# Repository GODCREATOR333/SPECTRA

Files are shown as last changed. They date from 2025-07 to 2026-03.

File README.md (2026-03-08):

## Abstract  
SPECTRA is a **laser steering system** based on a single-stage, direct-drive galvanometer.  
It uses a **voice-coil actuator** with a mirror assembly for high-speed angular control.  
A **custom differential photodiode position sensor** is being developed for feedback in this configuration.  

---

## Current Status  
- Functional CAD prototype fabricated and tested.  
- Operated at ~10% scanning speed in open-loop mode.  
- Closed-loop implementation (PID, LQR, MPC) under development.  

---

## Figures  

**Prototype:**  
SPECTRA CAD Prototype  

**Demonstration Video:**
Demo video

**Custom Physics Engine To Simulate Ray-plane intersection, Forward Kinematics, Inverse Kinematics, Control Strategies**
phy_engine_demo

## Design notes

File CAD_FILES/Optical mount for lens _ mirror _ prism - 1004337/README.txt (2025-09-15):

Optical mount for lens / mirror / prism  by dmarett on Thingiverse: https://www.thingiverse.com/thing:1004337

Summary:
This is a kinematic optical platform mount designed to fit onto a regular optical breadboard using 1/4-20 mounting holes (or metric).  It uses a mounting arm (PM1 style, see separate PM1 file ) to hold a square optical component against the lower platform. It uses 6-32 screws with knobs to control the movement of the platform left-right and pivot up-down. Mounting screw is 6-32 and can mount onto a steel 1/2 inch post with a 6-32 thread, or a 3D printed post (see separate file). The component requires a number of metal parts:Parts:2  6-32 x 3/8" internally threaded standoffs4  6-32 nuts1 6-32 x 1/4" screw2  6-32 x 1/2" screws (platform mount)2  6-32 x 1.5" screws1  6-32 x 3/4" screw (ball mount)2  1/2" springs with hook ends4  7/16" x 1/16" aluminum pins

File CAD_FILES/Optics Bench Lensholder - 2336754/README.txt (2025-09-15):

Optics Bench Lensholder by polyfractal on Thingiverse: https://www.thingiverse.com/thing:2336754

Summary:
Optical benches are expensive, but relatively simple devices.  I needed to test a multi-lens setup for a project I'm working but didn't want to shell out for an expensive optical bench. My experiment can tolerate the accuracy of 3d printed parts, hence these models :)  This is a fully printable adjustable lensholder which mounts onto an aluminum extrusion as the rail.  The lens is held in place by three sliders which have slots to grip the lens.  Each slider is held by a bolt and friction.  Holders are mounted via t-slot nuts that can slide up/down the extrusion.  The model is somewhat parametric, in that you can adjust the height of the holder and the maximum lens diameter that can be mounted.The sliders grip lenses 1-3mm in width the best, but could easily be modified to grip larger lenses (although I haven't fiddled with that yet, since all my lenses are small).Special thanks to:aubenc for the Knurled Surface Library (used on the bolts)daGIZmo for his T-Slot Nut (used as a base for the extrusion nut)rcolyer for his Metric Screw Threads, Holes, Bolts, Nuts, and Rods Library

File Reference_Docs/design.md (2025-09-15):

---

**Part 1: The Core Principles (The Physics)**

**The 2θ Rule**
For every 1 degree of mechanical rotation of your mirror (θ), the reflected laser beam will move by 2 degrees of optical angle (2θ). This is the foundation of all calculations.

**The Scanning Equations**

* **Simple Approximation:**
  Total scan length I = 2 \* d \* tan(θ\_optical). Good for quick estimates.

* **Accurate Cartesian Model:**
  Accounts for the separation (e) between the mirrors.

  ```
  y = d * tan(θy)
  x = (e + d / cos(θy)) * tan(θx)
  ```

  These equations are what you will use in your simulation to predict distortion.

---

**Part 2: The Mechanical Design Blueprint (The Hardware)**

Your physical build must prioritize speed and precision.

* **Orthogonal Design**
  Mount your two VCMs perpendicularly (at 90 degrees). This is simpler, more rigid, and easier to model than angled designs.

* **Minimize Mirror Separation (e)**
  This is the distance between the X and Y pivot axes. It is the primary cause of pincushion distortion. Your #1 mechanical goal is to get this distance as close to zero as possible.

* **Low Mirror Inertia**
  Use the smallest and lightest mirrors possible. Mirror mass is the enemy of speed. A heavy mirror will be slow, overshoot, and vibrate.

* **Pivot Point Alignment**
  The laser beam must strike the mirror surface directly on its physical axis of rotation. Any offset will cause a "wobble" (translation error) that is very difficult to correct.

* **Absolute Rigidity**
  The mounts holding the VCMs and the mirror brackets must have zero flex. Rigidity is essential for precision.

* **Design for Adjustment**
  Do not build a fixed system. Design in micro-adjustments from the start. Use slotted holes for the VCM mounts and push-pull screws for the laser diode mount to allow for fine-tuning of angles and positions during the physical build phase.

* **Plan for Feedback**
  Design your VCM/mirror assembly with a feature (like a small tab or "flag" on the back) that can be used to interrupt an optical sensor. You must accommodate this sensor in your mechanical design from the start.

---

**Part 3: The Electronics & Control Architecture (The Brains)**

For your goals of stabilization and compensation, the control system is non-negotiable.

* **Closed-Loop is Mandatory**
  You cannot achieve vibration cancellation with an open-loop system. You must have real-time feedback.

* **Two-Loop Control**

  * **Outer Loop:** The IMU detects vibration and tells the system where the laser spot needs to go to compensate.
  * **Inner Loop:** A high-speed PID loop uses a dedicated position sensor to make sure the mirror gets to that target position as quickly and accurately as possible.

* **Essential Components**

  * **Microcontroller:** A fast MCU like the Teensy 4.1 is a great choice.
  * **External DAC:** You must use an external Digital-to-Analog Converter (e.g., a 12-bit or 16-bit SPI DAC). The built-in "analog" outputs on most MCUs are unsuitable.
  * **Motor Driver:** An amplifier to take the small signal from the DAC and provide enough current to drive the VCM coils.

* **Sensor Architecture**
  You need three distinct sensor types for different roles.

  | Component           | Sensor Type           | Role                                                                  | When It's Used                                              |
  | ------------------- | --------------------- | --------------------------------------------------------------------- | ----------------------------------------------------------- |
  | Optical Endstops    | Digital (ON/OFF)      | Homing & Safety. Finds the mechanical limits.                         | Once at startup, and for fault protection.                  |
  | Proportional Sensor | Analog (Proportional) | Real-Time Position Feedback. The heart of the inner control loop.     | Constantly, thousands of times per second during operation. |
  | IMU                 | Digital Data          | External Disturbance Detection. Provides the goal for the outer loop. | Constantly, to detect vibration.                            |

---

**Part 4: Your End-to-End Design Workflow (The Process)**

This is your master plan, which correctly integrates all the above points.

1. **Design in CAD**
   Create the physical parts. This is your "perfect world" model where you will measure the initial parameters (e, d, mirror sizes, etc.) for your different design configurations. Remember to build in the adjustment mechanisms.

2. **Simulate in Manim**
   Use Manim as your virtual lab. Feed it the parameters from your CAD models to:

   * Visualize Distortion: See the pincushion effect for each design.
   * Check for Beam Clipping: Ensure the laser doesn't fall off the mirrors at extreme angles.
   * Test Sensitivity: Intentionally add small errors (+0.5mm offset, 89° angle) to see how robust your design is.

3. **Build & Align (The Mechanical True-Up)**
   3D print or machine your best design. Use the built-in adjustment features to physically align the laser and galvos as perfectly as possible.

4. **Calibrate & Correct (The Software Fix)**
   This is the final step that replaces "hope" with engineering. Write software to map your system's real-world errors and create a Correction Lookup Table (LUT). Your control software will then use this map to send pre-distorted commands, ensuring the final output on the screen is perfect.

---

You have a clear, thorough, and professional plan. The path from concept to a high-performance system is laid out before you.

Good luck, and happy designing.

---

------------------- Thingverse Stuff i am using to give to references and citations -----------------

https://www.thingiverse.com/thing:2336754  ---creator polyfractal on thingverse

https://www.thingiverse.com/thing:1004337/ ---creator dmarett on thingverse

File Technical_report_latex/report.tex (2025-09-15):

\documentclass[12pt]{article}
\usepackage[utf8]{inputenc}
\usepackage{subcaption}  
\usepackage{graphicx}
\usepackage{float}
\usepackage{geometry}
\usepackage{amsmath}
\usepackage{amssymb}
\usepackage{xcolor}
\usepackage{lipsum} % For placeholder text

\geometry{a4paper, margin=1in}
\pagestyle{empty} % No page numbers

\begin{document}

% ===================================================================
% PAGE 1: CLASSIFICATION NOTICE
% ===================================================================
\begin{center}
    \vspace*{1cm}
    {\Huge \textbf{\textcolor{red}{TOP SECRET // FOR INTERNAL USE ONLY}}}
    
    \vspace{2cm}
    \fbox{\parbox{0.8\textwidth}{
        \centering
        \Large \textbf{CLASSIFICATION NOTICE} \\
        \vspace{0.5cm}
        \normalsize
        This document contains proprietary and confidential information pertaining to advanced research and development. The information is the exclusive property of the project lead and associated institution.
        
        \vspace{0.5cm}
        Unauthorized access, reproduction, distribution, or disclosure of this material, in whole or in part, is strictly prohibited. Violators will be subject to the fullest extent of applicable institutional and civil policies.
        
        \vspace{0.5cm}
    }}

    \vspace{3cm}
    \begin{tabular}{ll}
        \textbf{STUDENT NAME:} & S. HARI PREETHAM \\
        \textbf{SUPERVISING AUTHORITY:} & DR. A. CHENNAKESAVA REDDY \\
        \textbf{INSTITUTION:} & JNTUH UCESTH \\
    \end{tabular}
    
    \vspace{2cm}
    {\large \textit{Handle with extreme care. Information contained herein is critical to ongoing research objectives.}}

    \vfill
    {\textbf{\textcolor{red}{CONFIDENTIAL}}}
\end{center}

\newpage

% ===================================================================
% PAGE 2: TITLE PAGE
% ===================================================================
\begin{titlepage}
    \centering
    {\Large A Project Report on} \\
    \vspace{1.5cm}
    {\Huge \textbf{
Real-Time Precision Actuation in Laser Steering Systems \\[0.1cm]
via Visual-Inertial Fusion and Active\\[0.3cm] Vibration Compensation
}}

    \vspace{2cm}
    
    {\large Submitted by:} \\
    \vspace{0.5cm}
    {\Large \textbf{S HARI PREETHAM}} \\
    {\large 21011P0329} \\
    \vspace{1.5cm}
    
    {\large Under the Esteemed Guidance of} \\
    \vspace{0.5cm}
    {\Large \textbf{DR. A. CHENNAKESAVA REDDY}} \\
    {\large Senior Professor, Department of Mechanical Engineering} \\
    \vfill
    
    % \includegraphics[width=0.3\textwidth]{logo.png} \\
    % \vspace{1cm}
    
    {\Large \textbf{JAWAHARLAL NEHRU TECHNOLOGICAL \\[0.1cm] UNIVERSITY HYDERABAD}} \\
    \vspace{0.2cm}
    {\large UNIVERSITY COLLEGE OF ENGINEERING SCIENCE AND TECHNOLOGY, HYDERABAD} \\ [0.1cm]
    \vspace{1.5cm}
    
    {\large August 2025}
\end{titlepage}

% ===================================================================
% TABLE OF CONTENTS
% ===================================================================
\pagestyle{plain}
\pagenumbering{roman} % Use roman numerals (i, ii, iii) for front matter
\tableofcontents
\newpage
\pagenumbering{arabic} % Switch back to arabic numerals (1, 2, 3) for the main document

% ===================================================================
% PAGE 3: ABSTRACT, PROBLEM STATEMENT, NOVELTY
% ===================================================================
\pagestyle{plain} % Enables page numbering (e.g., 1, 2, 3...)
\setcounter{page}{1} % Resets the page counter to start at 1

\section*{Abstract}

Conventional laser-based weeding systems, while a promising chemical-free alternative in precision agriculture, rely on high-mass platforms with passive mechanical isolation. This brute-force approach to stabilization necessitates the use of high-power pulsed lasers, which significantly increases the system's cost, complexity, safety concerns, and energy requirements.

This project proposes a low-cost, lightweight, control-centric paradigm: an active vibration compensation framework engineered from salvaged mechatronic components. The system integrates both inertial (IMU) and vision-based feedback to dynamically track and eliminate line-of-sight (LOS) jitter in real-time. This active stabilization enables the effective use of safe, low-power, continuous-wave (CW) lasers. Custom galvanometers, constructed from repurposed Hard-Disk Drive (HDD) and optical drive actuators, are governed by high-bandwidth control systems (PID, LQR, MPC). These controllers are based on state-space models derived from experimental system identification and Kalman filtering.

To complement the core stabilization, a computer vision pipeline is implemented for real-time plant versus weed classification and tracking, utilizing pre-trained deep learning models such as YOLOv8 for detection and DeepSORT/ByteTrack for object tracking. This enables robust visual servoing, locking the laser onto dynamic weed targets even under significant platform motion. While the primary application domain is agricultural automation, the core innovation—high-fidelity stabilization via hybrid sensor fusion and AI-guided control—is fundamental to defense, aerospace, and medical robotics.

\vspace{1cm}

\section*{Problem Statement and Motivation}

The deployment of precision laser systems on mobile platforms is severely hampered by several key challenges that current solutions fail to adequately address:
\begin{itemize}
    \item \textbf{Prohibitive Cost and Bulk:} Existing laser steering platforms depend on high-end, laboratory-grade galvanometers or heavy, complex gimbal mechanisms. These systems are expensive, bulky, and unsuitable for lightweight, cost-sensitive mobile applications like agricultural robots.
    \item \textbf{Unaddressed Mechanical Disturbance:} The majority of existing systems are designed for stationary or mechanically isolated platforms. The critical problem of maintaining real-time pointing accuracy under dynamic disturbances (e.g., vehicle vibration, terrain-induced movement) remains largely under-explored.
    \item \textbf{Lack of Sensor Fusion for Beam Control:} While sensor fusion is ubiquitous in navigation and robotics, its specific application to real-time beam steering and actuation control is a nascent field. There is a significant gap in integrating visual and inertial data to directly compensate for beam deviation.
    \item \textbf{Absence of Real-World Performance Metrics:} The literature lacks systematic experimental evaluation of actuation accuracy under vibration. Key performance metrics such as jitter suppression, settling time, and overshoot on disturbed platforms are not well-studied, making it difficult to compare system efficacy.
\end{itemize}

\vspace{1cm}

\section*{Novelty and Contribution}

This project makes several novel contributions to the field of mechatronics and control systems:
\begin{itemize}
    \item \textbf{Resource-Constrained Mechatronics:} It demonstrates that low-cost, salvaged hardware from e-waste can achieve high-precision control performance when coupled with modern software techniques, offering a viable alternative to expensive off-the-shelf components.
    \item \textbf{Hybrid AI + Control Stack:} It pioneers the integration of deep-learning-based computer vision with classical and modern control theory (PID, LQR, MPC) for active visual servoing in a precision actuation context.
    \item \textbf{Visual-Inertial Fusion for Disturbance Rejection:} It applies cutting-edge mapping and localization concepts (Visual-Inertial SLAM) not for navigation, but as a core component of a disturbance rejection framework for a dynamic targeting system.
    \item \textbf{Broad Impact Framework:} The core disturbance rejection and active stabilization framework is domain-agnostic and directly applicable to other high-stakes fields, including aerospace (satellite laser communication), defense (target tracking, counter-UAV systems), and medical optics.
\end{itemize}

\newpage

% ===================================================================
% CHAPTER 2: THEORETICAL FRAMEWORK
% ===================================================================
\section{Theoretical Framework}

The ability to precisely and rapidly steer a laser beam requires a robust mathematical model of the system's mechanics and optics.
 This section develops this framework, beginning with the fundamental laws of reflection and culminating in the kinematic models that translate desired target coordinates into physical actuator commands.

\subsection{Principle of Reflection and the 2\(\theta\) Rule}

The kinematic model is built upon the law of reflection. A critical and direct consequence for dynamic systems is the 2\(\theta\) Rule: a mechanical rotation of a mirror by an angle \(\theta\) deflects the reflected optical path by \(2\theta\).

This angular amplification is a direct result of the geometry.
 When the mirror plane rotates by \(\theta\), the mirror's normal vector must also rotate by the same angle
  \(\theta\). This rotation changes the angle of incidence by \(\theta\). To satisfy the law of reflection
  with respect to this new normal, the angle of reflection must also change by \(\theta\).
   The total deflection is the sum of these two changes, resulting in a robust and predictable deflection 
   of precisely \(2\theta\). This effect provides a crucial mechanical advantage, allowing small, 
   high-speed rotations to produce a large angular sweep of the laser beam.

\subsubsection{A First Approximation: Planar Projection}
As a first-order model for a single-axis scanner, we can directly apply the 2\(\theta\) rule using basic trigonometry. Consider a single mirror pivoting at the origin and deflecting a laser beam onto a flat screen positioned at a perpendicular distance \(d\).

The optical deflection angle is \(2\theta\). In the right-angled triangle formed by the pivot point, the center of the screen, and the laser spot, the displacement of the spot (\(x\)) is the side opposite to this angle. Therefore, the relationship is given by:
\begin{equation}
    \tan(2\theta) = \frac{\text{opposite}}{\text{adjacent}} = \frac{x}{d}
\end{equation}
Solving for the displacement \(x\) gives our first approximation:
\begin{equation}
    x = d \tan(2\theta)
\end{equation}
While simple and useful for basic estimations, this model is insufficient for a high-fidelity 2D system because it fails to account for the sequential reflections and the physical distance between the two mirrors. For a rigorous model, we must therefore use the vector form of reflection.

\begin{figure}[H]
    \centering
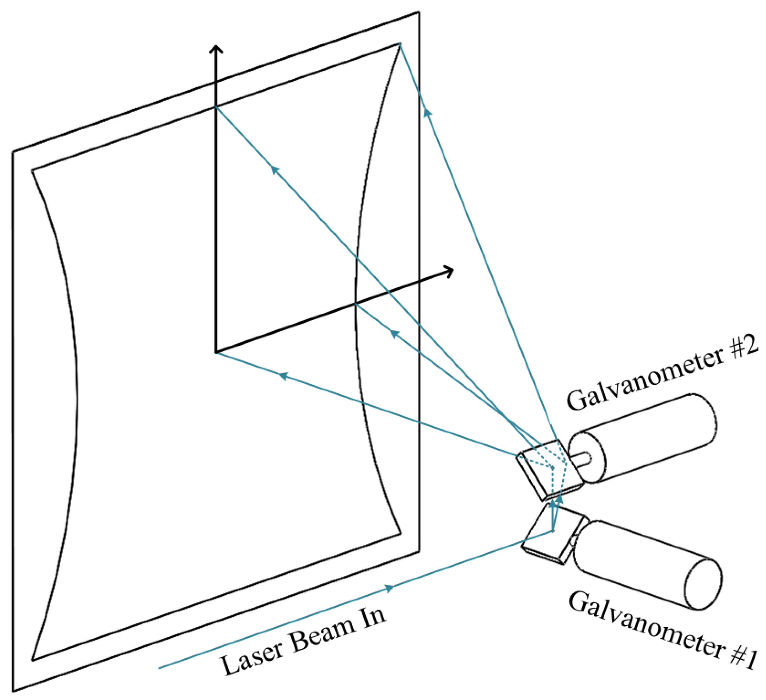
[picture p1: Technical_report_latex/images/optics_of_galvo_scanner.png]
     % replace with your file name
    \caption{Geometric illustration of the principle of reflection and the $2\theta$ rule.}
    \label{fig:reflection_2theta}
\end{figure}

Therefore, by using a dual-axis galvanometer setup, the laser beam can be directed to any point within a defined area on the X–Y plane. The size of this area is determined by the mirror dimensions, the angular range of rotation, and the distance between the mirror system and the projection surface.     
\subsubsection{Vector Form of Reflection}
Let \(\vec{V}\) be the unit vector representing the direction of the incoming laser beam, and let \(\vec{N}\) be the unit normal vector of the mirror surface. The resulting reflected vector, \(\vec{R}\), is given by:
\begin{equation}
    \vec{R} = \vec{V} - 2(\vec{V} \cdot \vec{N})\vec{N}
    \label{eq:vector_reflection}
\end{equation}
This equation forms the basis of our kinematic model. 

\subsection{Forward Kinematics: From Mirror Angles to Screen Coordinates}

Forward kinematics provides a mathematical model to calculate the final laser spot position on the screen, \((X_f, Y_f)\), from a given set of mechanical mirror angles, \((\theta_x, \theta_y)\). To construct this model, we first define a standard 3D Cartesian coordinate system:

\begin{itemize}
\item The origin, \([0,0,0]\), is defined as the pivot center of the first mirror (the X-mirror).
\item The \textbf{Z-axis} represents the path of the incoming laser beam.
\item The \textbf{X-mirror} is responsible for horizontal deflection. It pivots around the \textbf{Y-axis} by a mechanical angle \(\theta_y\).
\item The \textbf{Y-mirror} is responsible for vertical deflection. It is positioned at a distance \(e\) along the X-axis from the first mirror. It pivots around an axis parallel to the \textbf{X-axis} by a mechanical angle \(\theta_x\).
\end{itemize}

The initial state is an incoming laser beam traveling along the Z-axis, represented by the vector \(\vec{V}_{in} = [0, 0, 1]^T\). The undeflected normals of the mirrors, \(\vec{N}_{x0}\) and \(\vec{N}_{y0}\), are typically oriented at 45 degrees to the Z-axis to correctly fold the optical path.

A rotation of a mirror changes its normal vector. The new normal is found by applying a 3D rotation matrix to the initial normal vector.
\begin{itemize}
\item \textbf{Rotation around X-axis} (for Y-mirror, angle \(\theta_x\)):
\begin{equation}
\mathbf{R}_x(\theta_x) = \begin{bmatrix} 1 & 0 & 0 \\ 0 & \cos\theta_x & -\sin\theta_x \\ 0 & \sin\theta_x & \cos\theta_x \end{bmatrix}
\end{equation}
\item \textbf{Rotation around Y-axis} (for X-mirror, angle \(\theta_y\)):
\begin{equation}
\mathbf{R}_y(\theta_y) = \begin{bmatrix} \cos\theta_y & 0 & \sin\theta_y \\ 0 & 1 & 0 \\ -\sin\theta_y & 0 & \cos\theta_y \end{bmatrix}
\end{equation}
\end{itemize}

\subsubsection{Full Path Algorithm}
The final direction of the laser beam is calculated through a sequence of two reflections:
\begin{enumerate}
\item \textbf{First Reflection (X-mirror):} The X-mirror's normal vector is updated based on its rotation: \(\vec{N}_{x} = \mathbf{R}_y(\theta_y)\vec{N}_{x0}\). The incoming beam reflects off this surface, resulting in a new direction vector: \(\vec{R}_1 = \vec{V}_{in} - 2(\vec{V}_{in} \cdot \vec{N}_{x})\vec{N}_{x}\). The components of \(\vec{R}_1\) are now trigonometric functions of the angle \(\theta_y\).
\item \textbf{Second Reflection (Y-mirror):} The Y-mirror's normal vector is similarly updated: \(\vec{N}_{y} = \mathbf{R}_x(\theta_x)\vec{N}_{y0}\). The beam from the first mirror, \(\vec{R}_1\), is the incoming vector for this reflection. The final direction vector is therefore: \(\vec{R}_{final} = \vec{R}_1 - 2(\vec{R}_1 \cdot \vec{N}_{y})\vec{N}_{y}\).
\end{enumerate}
It is critical to note that during this second reflection, the dot product term \((\vec{R}_1 \cdot \vec{N}_{y})\) mathematically entangles the two rotation angles. Because \(\vec{R}_1\) is a function of \(\theta_y\) and \(\vec{N}_{y}\) is a function of \(\theta_x\), the resulting vector \(\vec{R}_{final}\) contains complex, non-linear cross-coupled terms, making it impossible to separate the influence of each angle cleanly.

\subsubsection{Ray-Plane Intersection and Pincushion Distortion}
With the final direction vector \(\vec{R}_{final} = [R_x, R_y, R_z]^T\), we can determine its intersection with a screen plane. The final ray originates from the pivot point of the Y-mirror, which is located at \(\vec{P}_y = [e, 0, 0]^T\). The parametric equation for this ray is \(\vec{P}(t) = \vec{P}_y + t \cdot \vec{R}_{final}\).

The screen is a plane defined by the equation \(z=d\), where \(d\) is the perpendicular distance from the Y-mirror's pivot axis to the screen. To find the intersection point, we solve the z-component of the parametric equation for the parameter \(t\):
\begin{equation}
0 + t \cdot R_z = d \implies t = \frac{d}{R_z}
\end{equation}
Substituting \(t\) back into the x and y components gives the final coordinates \((X_f, Y_f)\):
\begin{equation}
X_f = e + t \cdot R_x = e + d \frac{R_x}{R_z}
\end{equation}
\begin{equation}
Y_f = 0 + t \cdot R_y = d \frac{R_y}{R_z}
\end{equation}
This model fully describes the geometry of the system. It also reveals the source of pincushion distortion. The final X-coordinate depends not just on its own angle but also on the path length to the screen. This path length is modulated by the tilt of the Y-mirror, causing the scan field to become wider at the top and bottom edges, which creates the characteristic pincushion shape.

\subsubsection{Matrix Representation of the Kinematic Chain}

To more clearly illustrate the coupling between the mirror rotations, we can represent the reflection operation itself as a matrix transformation. For a given mirror normal \(\vec{N}\), the reflection matrix \(\mathbf{M}_{ref}(\vec{N})\) that transforms an incoming vector \(\vec{V}\) to a reflected vector \(\vec{R}\) is given by:

\begin{equation}
\mathbf{M}_{ref}(\vec{N}) = \mathbf{I} - 2(\vec{N} \otimes \vec{N}) = \begin{bmatrix} 1 - 2N_x^2 & -2N_xN_y & -2N_xN_z \\ -2N_xN_y & 1 - 2N_y^2 & -2N_yN_z \\ -2N_xN_z & -2N_yN_z & 1 - 2N_z^2 \end{bmatrix}
\end{equation}
where \(\mathbf{I}\) is the identity matrix and \(\otimes\) denotes the outer product.

Using this representation, the entire forward kinematic chain can be expressed as a single composite transformation matrix, \(\mathbf{M}_{total}\), acting on the initial beam vector:

\begin{enumerate}
\item The reflection matrix for the X-mirror, \(\mathbf{M}_{ref,X}\), is a function of its normal, \(\vec{N}_x\), which in turn depends on the angle \(\theta_y\).
\item The reflection matrix for the Y-mirror, \(\mathbf{M}_{ref,Y}\), is a function of its normal, \(\vec{N}_y\), which depends on the angle \(\theta_x\).
\item The final direction vector is therefore given by the product of these matrices:
\begin{equation}
\vec{R}_{final} = \mathbf{M}_{ref,Y}(\theta_x) \cdot \mathbf{M}_{ref,X}(\theta_y) \cdot \vec{V}_{in}
\end{equation}
\end{enumerate}

This formulation makes the "entanglement" explicit. The total transformation matrix is the product of two matrices, each dependent on one of the control angles. Because matrix multiplication is not commutative \((\mathbf{A}\mathbf{B} \neq \mathbf{B}\mathbf{A})\), the final result is a complex function where the influences of \(\theta_x\) and \(\theta_y\) are thoroughly mixed. This elegantly demonstrates why a simple, separable analytical solution for the inverse kinematics is not possible.

\subsection{Inverse Kinematics: The Challenge of Target-to-Angle Mapping}

For any practical control application, we must solve the inverse problem: given a desired target on the screen \((X_{target}, Y_{target})\), what are the required mirror angles \((\theta_x, \theta_y)\)? This is the inverse kinematics (IK) problem.

The forward kinematic model, while accurate for simulation, is insufficient for real-time control, especially on a mobile platform, because:
\begin{itemize}
\item The reference frame is no longer static; the entire scanner assembly, including the mirror pivots and the screen plane, is moving and vibrating relative to the world.
\item The system must solve for angles in real-time to track a target, compensating for both the target's position and the platform's own motion.
\item As demonstrated, the forward mapping \((X_f, Y_f) = f(\theta_x, \theta_y)\) is a complex, non-linear, and coupled function. A direct analytical inversion to find \((\theta_x, \theta_y) = f^{-1}(X_f, Y_f)\) is mathematically intractable for a real-time system.
\end{itemize}

\subsubsection{Analytical vs. Numerical IK}
An \textbf{analytical} solution would provide a direct, closed-form equation, e.g., \(\theta_x = f(X,Y)\). While derivable for highly simplified cases (e.g., assuming perfectly orthogonal, co-located mirrors), such solutions are brittle and fail to account for real-world mechanical realities, rendering them useless for a high-precision system.

A \textbf{numerical} solution iteratively finds the angles. This approach is more robust and can adapt to complex, non-ideal systems, which is essential for our application. We use the Jacobian-based iterative method.

\subsection{Numerical Solution: The Jacobian Iterative Method}

The Jacobian matrix, \(\mathbf{J}\), serves as a "sensitivity map." It relates infinitesimal changes in the input (mirror angles) to the resulting infinitesimal changes in the output (screen position). It is the matrix of all first-order partial derivatives of the forward kinematics function:
\begin{equation}
    \mathbf{J}(\boldsymbol{\theta}) = \begin{bmatrix} \frac{\partial X_f}{\partial \theta_x} & \frac{\partial X_f}{\partial \theta_y} \\ \frac{\partial Y_f}{\partial \theta_x} & \frac{\partial Y_f}{\partial \theta_y} \end{bmatrix}
\end{equation}
where \(\boldsymbol{\theta} = [\theta_x, \theta_y]^T\).

We use this matrix in an iterative algorithm to converge on the correct angles.

\subsubsection{Iterative Inverse Kinematic Algorithm}
\begin{enumerate}
    \item \textbf{Initialization (Step 0):} Identify the target position \(\vec{P}_{target} = [X_{target}, Y_{target}]^T\). Start with the current measured angles of the motors, \(\boldsymbol{\theta}_{current}\).
    \item \textbf{Calculate Current Position (Step 1):} Use the forward kinematics model to calculate the current laser position on the screen, \(\vec{P}_{current}\), based on \(\boldsymbol{\theta}_{current}\).
    \item \textbf{Find the Error (Step 2):} Calculate the error vector between the target and current position: \(\vec{e} = \vec{P}_{target} - \vec{P}_{current}\).
    \item \textbf{Calculate Jacobian (Step 3):} Compute the Jacobian matrix \(\mathbf{J}\) at the current angle configuration \(\boldsymbol{\theta}_{current}\).
    \item \textbf{Determine Angle Correction (Step 4):} The desired change in angles, \(\Delta\boldsymbol{\theta}\), can be found by "inverting" the Jacobian relationship \(\vec{e} \approx \mathbf{J} \Delta\boldsymbol{\theta}\). Instead of using a direct and potentially unstable inverse, we use the Jacobian transpose, which is computationally simpler and more stable:
    \begin{equation}
        \Delta\boldsymbol{\theta} = \alpha \mathbf{J}^T \vec{e}
    \end{equation}
    Here, \(\alpha\) is a small learning rate (a step size) that ensures a stable convergence.
    \item \textbf{Update Guess (Step 5):} Update the motor angles: \(\boldsymbol{\theta}_{new} = \boldsymbol{\theta}_{current} + \Delta\boldsymbol{\theta}\).
    \item \textbf{Repeat:} Set \(\boldsymbol{\theta}_{current} = \boldsymbol{\theta}_{new}\) and repeat from Step 1 until the magnitude of the error vector \(||\vec{e}||\) is below a desired tolerance.
\end{enumerate}
This iterative process allows the system to find the correct angles even for a complex, non-ideal mechanical setup and is the core of the high-level steering control.

\subsubsection{Limitations of the Jacobian Transpose Method}
While computationally efficient, this basic iterative method has a critical flaw for a physical system: it is unconstrained. The algorithm has no inherent knowledge of the galvanometer's mechanical limits. If a target is commanded near or outside the scanner's reachable workspace, this algorithm will calculate and command angles (e.g., \(\theta_x = 15^\circ\)) that are physically impossible for the actuator to achieve. This can lead to actuator saturation, instability, and unpredictable behavior at the edges of the workspace. For a robust, "battle-ready" system, we must be able to handle these physical constraints gracefully.

\subsection{Enhanced Solution: Constrained Optimization}

To address the limitations of the unconstrained approach, we re-frame the IK problem as a formal optimization problem. The goal is no longer just to find *any* solution, but to find the *best possible* solution that satisfies all physical constraints. This is achieved by finding the angle vector \(\vec{\theta}\) that minimizes a scalar Cost Function, \(C(\vec{\theta})\).

\subsubsection{The Cost Function}
The Cost Function mathematically defines the "total error" of the system, balancing pointing accuracy with adherence to physical limits.
\begin{equation}
C(\vec{\theta}) = \frac{1}{2} || \text{FK}(\vec{\theta}) - \vec{P}_{target} ||^2 + \beta H(\vec{\theta}, \vec{\theta}_{max})
\label{eq:cost_function}
\end{equation}

The function consists of two terms:
\begin{itemize}
\item \textbf{Accuracy Term:} \(\frac{1}{2} || \text{FK}(\vec{\theta}) - \vec{P}_{target} ||^2\) is the squared distance error. Minimizing this term drives the laser to the target.
\item \textbf{Constraint Term:} \(H(\vec{\theta}, \vec{\theta}_{max})\) is a \textbf{barrier function} that penalizes angles approaching their limits. A logarithmic barrier is used, which approaches infinity as any angle \(\theta_i\) nears its limit \(\pm\theta_{max}\), creating a "force field" that the optimizer will not violate.
\end{itemize}
The scalar weight \(\beta\) controls the strength of this barrier.

\subsubsection{Solution via Gradient Descent}
The cost function is minimized using the Gradient Descent algorithm, which iteratively updates the angles by taking steps in the direction opposite to the gradient of the cost function.
\begin{equation}
\vec{\theta}_{k+1} = \vec{\theta}_k - \alpha \nabla C(\vec{\theta}_k)
\end{equation}
The gradient \(\nabla C\) is derived from Equation \ref{eq:cost_function} and is composed of the gradient of both the accuracy and the barrier terms. The gradient of the accuracy term is found to be \(\mathbf{J}(\vec{\theta})^T \cdot (\text{FK}(\vec{\theta}) - \vec{P}_{target})\).

\vspace*{0.5cm}

This constrained optimization framework represents the final, robust solution. It leverages the efficiency of the Jacobian while formally incorporating actuator limits. This ensures that the calculated angles are always physically achievable, providing stable and predictable behavior across the entire workspace and preventing the controller from commanding impossible states. This is the core algorithm for the high-level steering controller.

\subsubsection{Algorithm Stability and Convergence}

The stability of the numerical IK solver is a critical consideration. Unlike an analytical solution, an iterative algorithm's performance is not guaranteed and depends on its formulation and tuning.

The proposed algorithm incorporates several features to ensure stable and predictable convergence:

\begin{itemize}
\item \textbf{Use of the Jacobian Transpose:} The choice of the Jacobian Transpose method, \(\Delta\boldsymbol{\theta} = \alpha \mathbf{J}^T \vec{e}\), over a direct matrix inverse, \(\Delta\boldsymbol{\theta} = \mathbf{J}^{-1} \vec{e}\), is a key stabilizing factor. The transpose method is less susceptible to issues with matrix singularities (positions where the inverse is undefined) and generally provides a smoother, more stable path towards the solution, even if it sometimes requires more iterations.

\item \textbf{The Learning Rate (\(\alpha\)):} The scalar step size, \(\alpha\), is a crucial tuning parameter. A small, fixed value for \(\alpha\) will be chosen to prevent the algorithm from taking excessively large steps. This prevents overshooting the target and ensures the iterative process does not become unstable or oscillate.

\item \textbf{Constraint Handling:} The inclusion of the logarithmic barrier function in the constrained optimization framework is another critical stabilizing feature. By preventing the solver from ever commanding angles outside the known physical limits of the actuator, it eliminates a major source of potential instability and ensures all commanded states are physically achievable.`

\end{itemize}

\textbf{Verification Method:}
The stability of the implemented algorithm will be verified experimentally. The system will be subjected to a series of step commands to various points within the workspace, including points at the extreme edges. The convergence of the error vector \(||\vec{e}||\) over the iterations will be plotted and analyzed. A stable system will demonstrate a smooth, monotonic decrease in error. Any oscillatory or divergent behavior will be addressed by tuning the learning rate \(\alpha\) and the barrier weight \(\beta\).
\newpage

% ===================================================================
% CHAPTER 3: MECHANICAL DESIGN
% ===================================================================
\section{Mechanical Design and System Architecture}

The efficacy of the laser stabilization and targeting system is fundamentally dependent on the precision, rigidity, and thermal stability of its mechanical architecture. This section details the design of the physical assembly, outlining the system layout, the novel solution for the kinematic mirror mounting, and the rationale behind the material selection and thermal management strategies.

\subsection{System Layout and Kinematic Mounting}

The system is configured as a traditional orthogonal two-axis scanner to produce a Cartesian motion profile. The primary actuators are two Voice Coil Motors (VCMs) salvaged from Hard Disk Drives (HDDs), chosen for their low inertia and high-speed response.

\begin{itemize}
\item The \textbf{X-axis galvanometer assembly} is mounted horizontally onto the main system baseplate. Its pivot axis is oriented vertically (\(Z_{axis}\)).
\item The \textbf{Y-axis galvanometer assembly} is mounted on a rigid, 90-degree vertical support structure. Its pivot axis is oriented horizontally (\(Y_{axis}\)).
\end{itemize}

Unlike commercial galvo scanners, the X-axis mirror subassembly is not a kinematic mount. Instead, it is secured by four M4 bolts with nut–washer sets to a rigid reference platform. Slots are included in the mount to allow linear adjustment of the interface between the X-axis and Y-axis structures. This design provides the flexibility to calibrate the inter-mirror distance for different mirror sizes and optical path requirements, rather than fixing the geometry permanently.

Both X- and Y-axis mounts incorporate embedded hexagonal cavities to seat metal hex nuts within the 3D-printed body. This reinforcement was necessary to withstand the flexural forces imposed by the strong permanent magnets of the HDD actuators. Tolerances in these assemblies are often below 1–2 mm, meaning that even slight deformation of the plastic body would cause misalignment or structural failure. The embedded nut design transfers clamping loads directly into the steel hardware, reducing stress concentration in the printed polymer and improving long-term rigidity.

The Y-axis vertical mount also uses through-holes and embedded nuts to achieve rigid mating with the baseplate, ensuring orthogonality between axes. To compensate for additive manufacturing limitations, the geometry was modified from the original HDD structure. The redesign introduced structural ribs, screw slots, and local thickening in high-stress regions to increase stiffness while keeping the assembly lightweight.
% ================== Part-Level Analysis ==================
\begin{figure}[H]
    \centering
    \begin{subfigure}[b]{0.48\textwidth}
        \centering
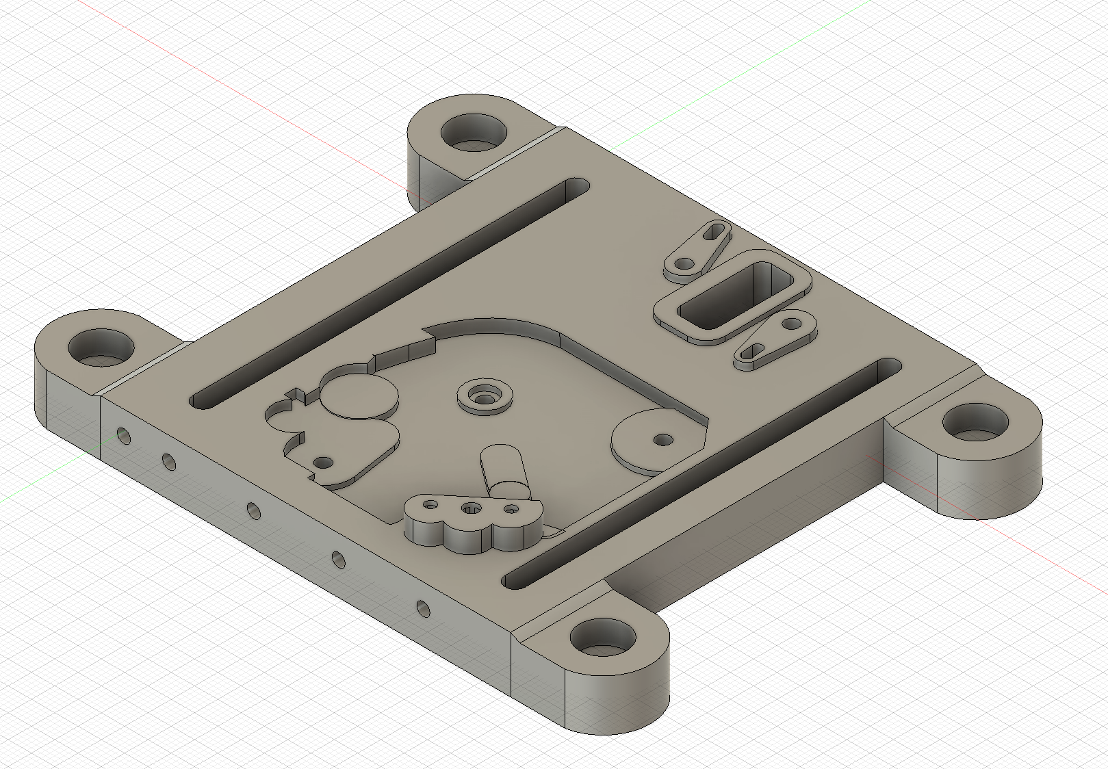
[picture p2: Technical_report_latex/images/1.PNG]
        
        \caption{X-axis VCM actuator mount}
        \label{fig:x_mount}
    \end{subfigure}
    \hfill
    \begin{subfigure}[b]{0.48\textwidth}
        \centering
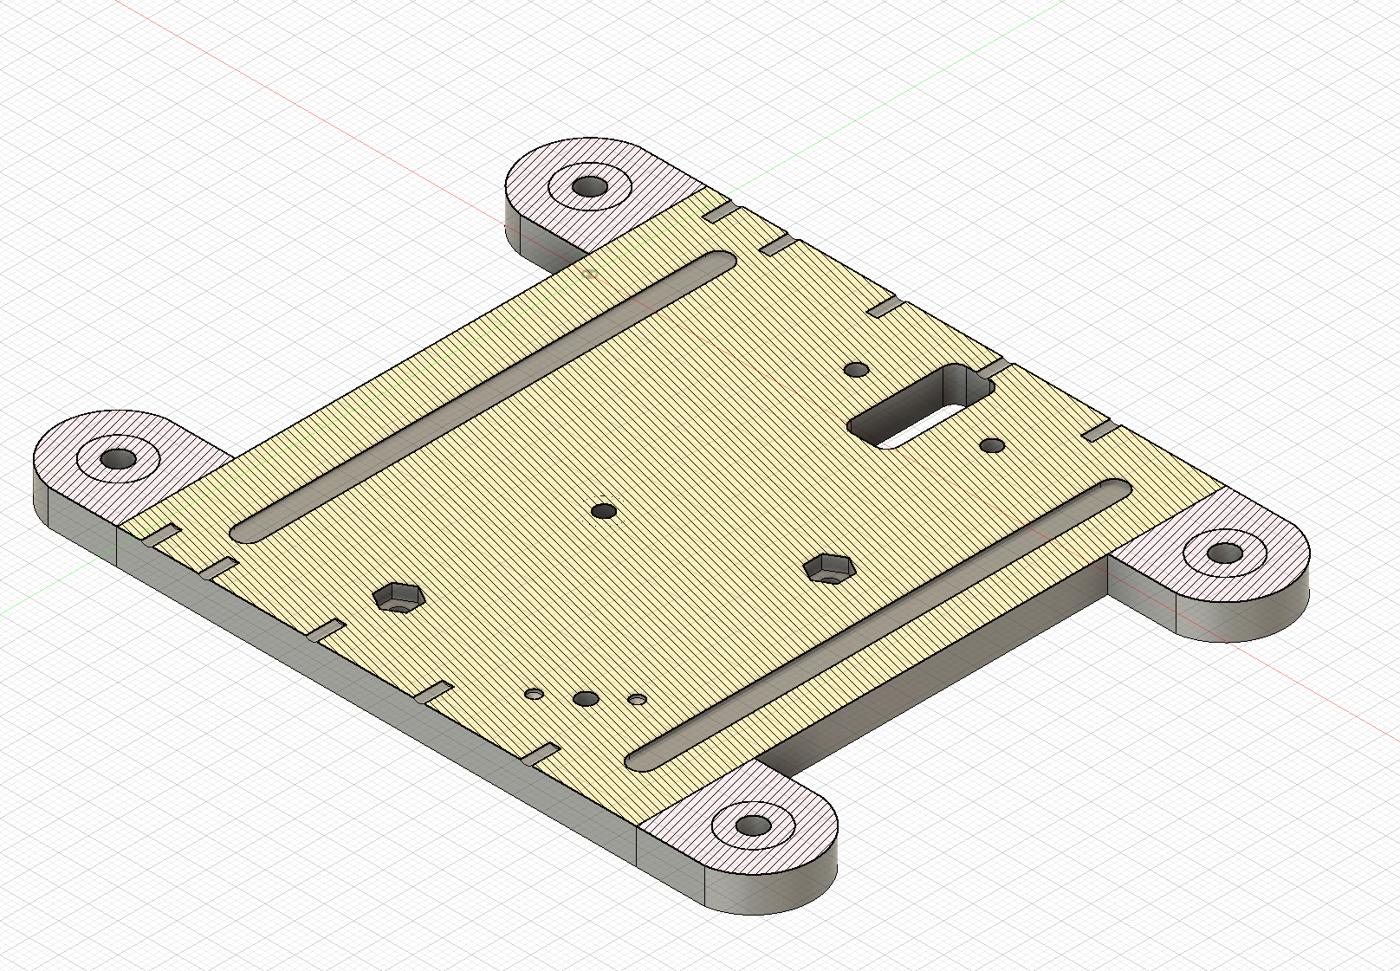
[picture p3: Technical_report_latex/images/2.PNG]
        
        \caption{Cross-section area analysis of X-axis mount}
        \label{fig:x_cross}
    \end{subfigure}
    \caption{X-axis actuator mount and corresponding cross-section analysis.}
    \label{fig:x_mount_combo}
\end{figure}

\begin{figure}[H]
    \centering
    \begin{subfigure}[b]{0.48\textwidth}
        \centering
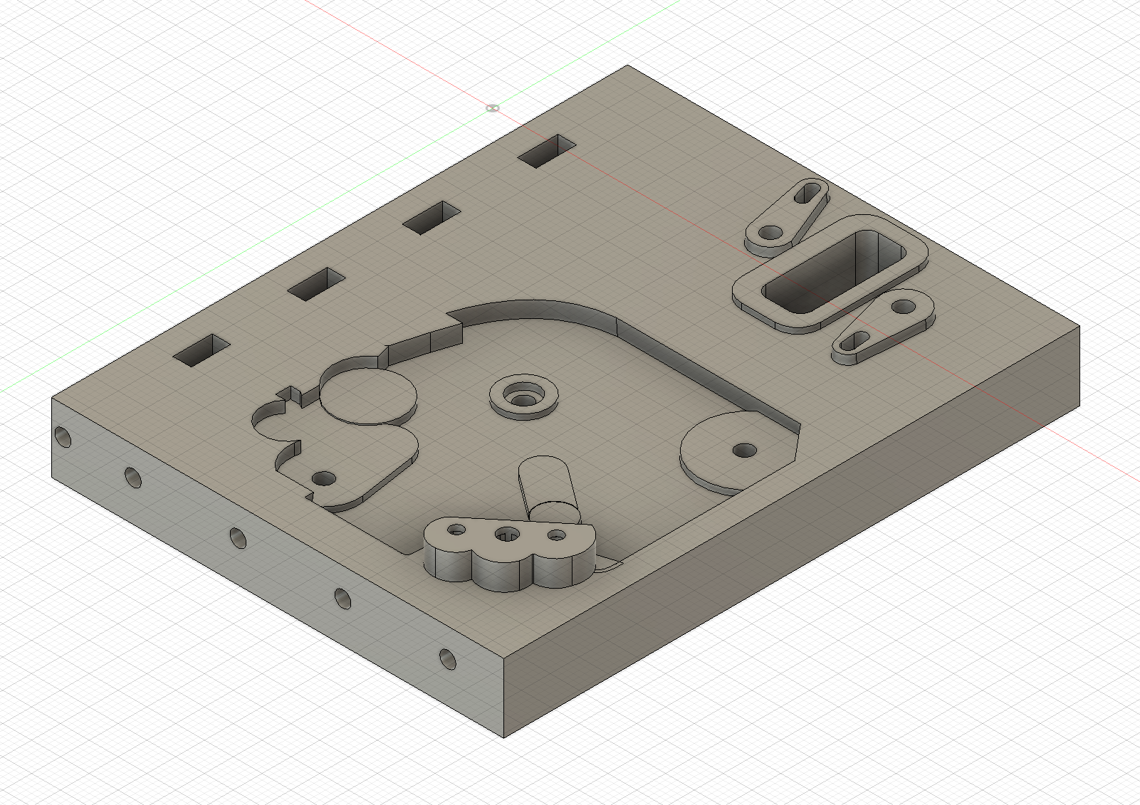
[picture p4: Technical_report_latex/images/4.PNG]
        
        \caption{Y-axis VCM actuator mount}
        \label{fig:y_mount}
    \end{subfigure}
    \hfill
    \begin{subfigure}[b]{0.48\textwidth}
        \centering
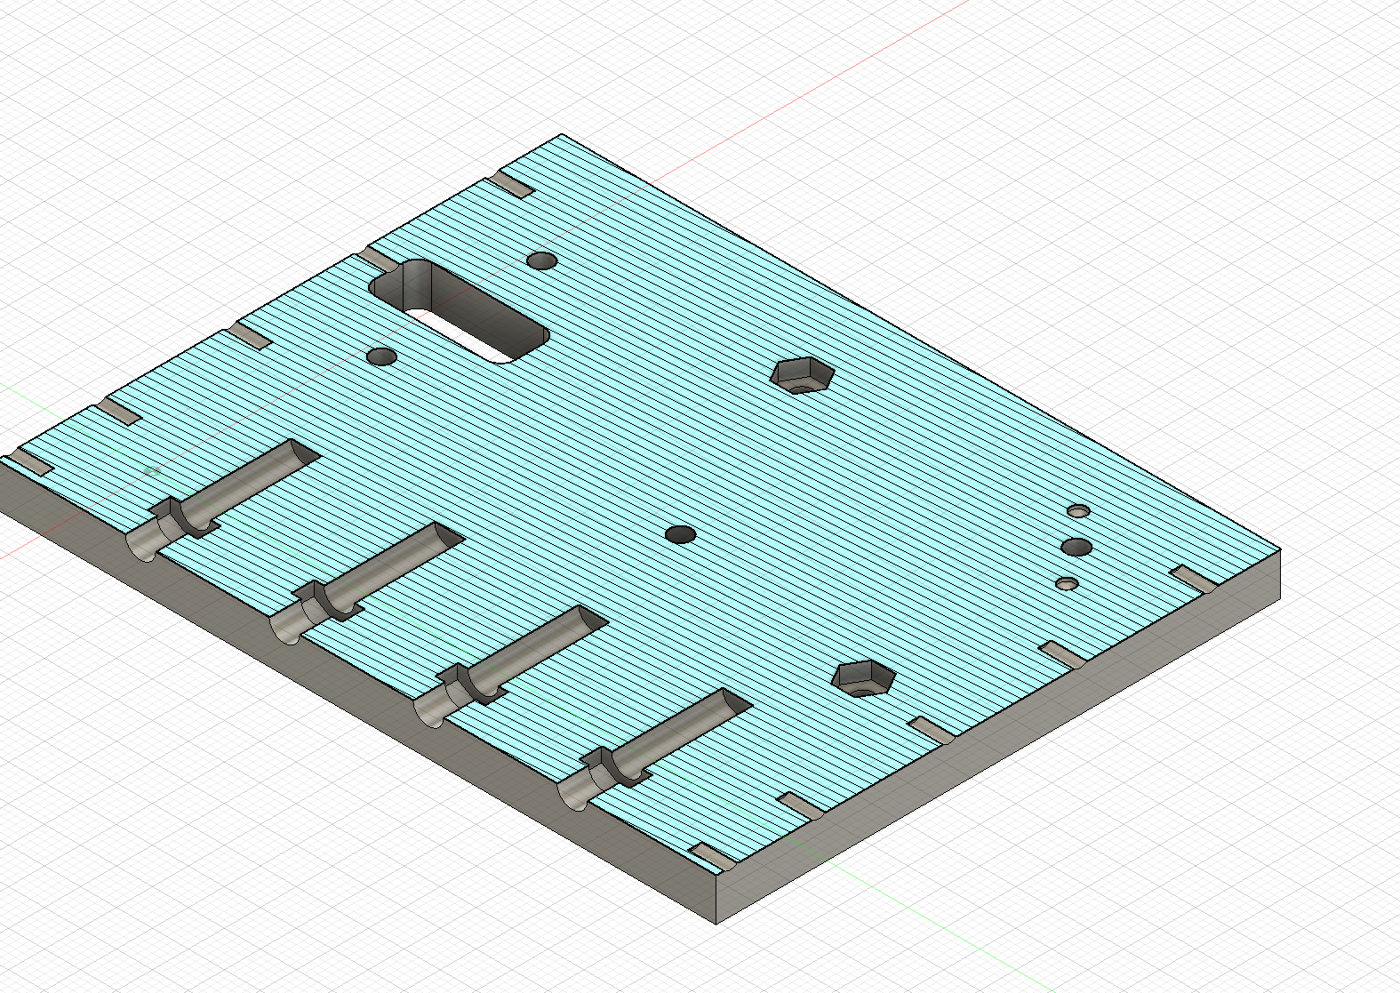
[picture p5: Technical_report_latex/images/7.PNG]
        
        \caption{Cross-section area analysis of Y-axis mount}
        \label{fig:y_cross}
    \end{subfigure}
    \caption{Y-axis actuator mount and corresponding cross-section analysis.}
    \label{fig:y_mount_combo}
\end{figure}

% ================== Assembly CAD & Structural Analysis ==================
\begin{figure}[H]
    \centering
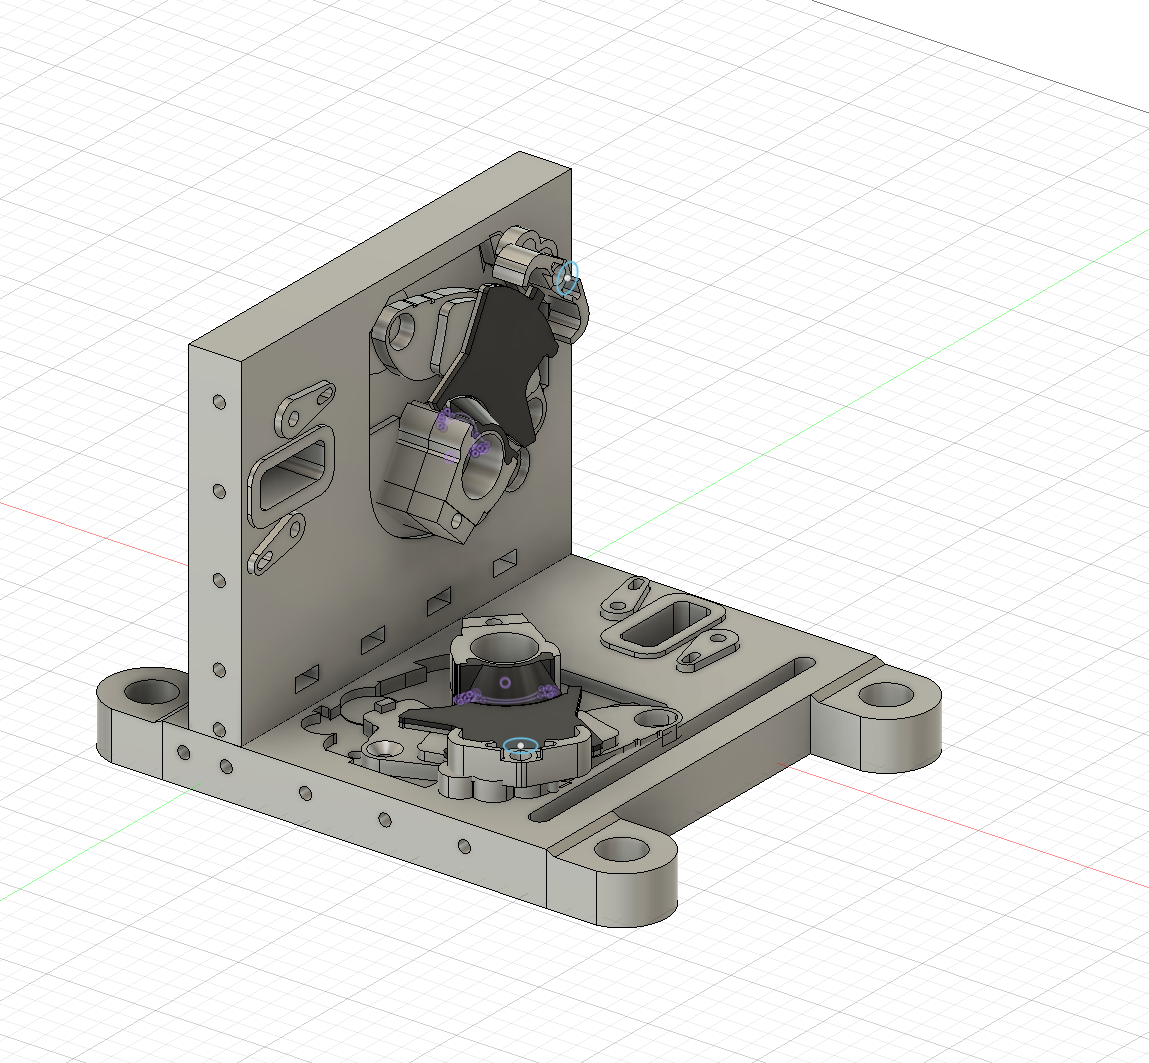
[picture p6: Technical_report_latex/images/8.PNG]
    
    \caption{CAD model of the complete dual-axis galvanometer assembly, showing orthogonal arrangement of VCM actuators and kinematic mounting points on the main baseplate.}
    \label{fig:assembly_cad}
\end{figure}

\begin{figure}[H]
    \centering
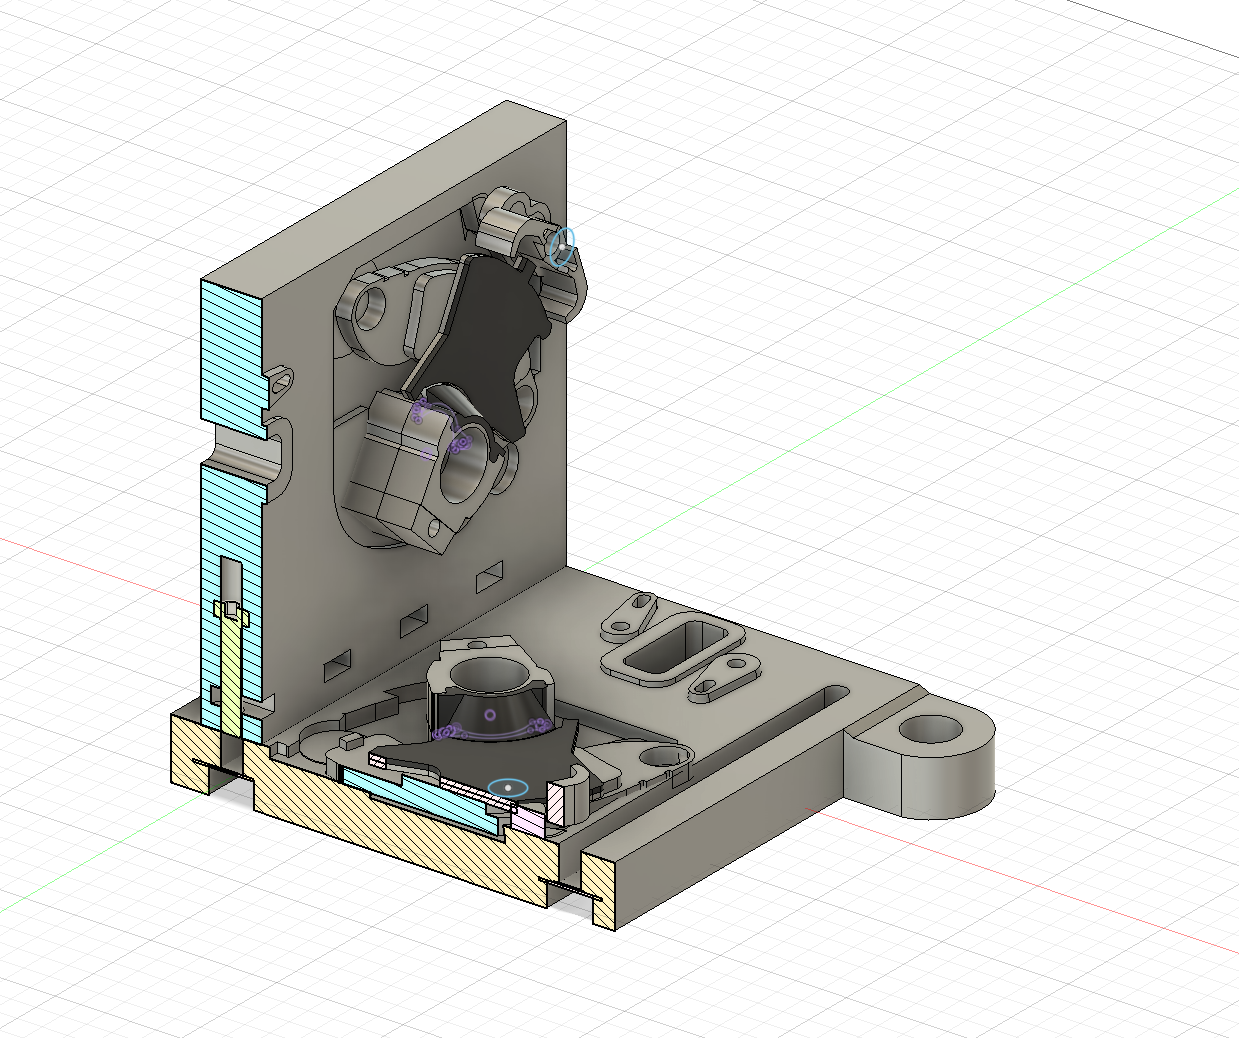
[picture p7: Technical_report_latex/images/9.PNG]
    
    \caption{Structural cross-section area analysis and mating surfaces of the full assembly. The mounts are fastened using M4 nuts, bolts, and washers.}
    \label{fig:assembly_analysis}
\end{figure}

% ================== Physical Prototype ==================
\begin{figure}[H]
    \centering
    \includegraphics[angle=-90, width=0.85\textwidth,
        trim={25cm 1cm 20cm 1cm}, clip]{./images/11.jpg}
    \caption{Photograph of the 3D-printed dual-axis galvanometer assembly.}
    \label{fig:assembly_prototype}
\end{figure}

\subsection{VCM Mirror Mount: The Decoupled Slotted-Plate Solution}

The core of the mechanical design addresses the kinematic mounting paradox, wherein the mirror's reflective surface must lie on the actuator's pivot axis, a volume physically occupied by the bearing assembly. To resolve this, a \textbf{decoupled, slotted-plate mounting system} was designed.

This system consists of a stationary plate, fabricated from the chosen polymer, which is mounted to the VCM's fixed base. A precision slot, with its centerline designed to be perfectly collinear with the VCM's axis of rotation, provides a rigid, kinematically correct guide for the mirror element. The moving arm of the VCM actuates the mirror via a small, custom-designed fork. This architecture provides superior geometric accuracy and rigidity compared to a cantilevered bracket by separating the function of alignment (handled by the stationary plate) from the function of actuation (handled by the moving arm).

% INSERT FIGURE: VCM Mount Design
\begin{figure}[H]
\centering
% \includegraphics[width=0.8\textwidth]{./images/your_vcm_mount_cad.png} % Replace with your filename
\caption{Detailed view of the custom slotted-plate mirror mount. The stationary plate provides a precise guide for the mirror, ensuring its reflective surface remains on the pivot axis.}
\label{fig:vcm_mount}
\end{figure}

\subsection{Material Selection and Thermal Management Strategy}

The selection of the fabrication material involved a critical trade-off analysis between mechanical performance and thermal stability. The primary heat sources are the VCM coils, which can reach elevated temperatures during high-duty cycle operation.

\subsubsection{Material Choice}
A \textbf{PLA+ (Professional PLA)} filament was selected for all 3D printed structural components. This decision prioritizes the material's superior mechanical properties at ambient temperatures. The higher Young's Modulus (stiffness) and lower susceptibility to creep under static load compared to other FDM materials like PETG are critical for maintaining the long-term dimensional stability and precision of the kinematic mounts and mirror alignment slots.

\subsubsection{Thermal Management}
To mitigate the risk of thermal deformation associated with PLA+'s low glass transition temperature (approx. 60°C), a \textbf{thermal break} is integrated into the mounting design. The VCM assemblies are mounted via metal standoffs, creating an insulating air gap that minimizes heat transfer to the PLA+ baseplate. Furthermore, thin \textbf{polyimide (Kapton) tape washers} are used at the screw-standoff interfaces. Kapton tape is a high-performance polymer film that serves as both a superior electrical insulator and a robust thermal insulator, effectively blocking the conductive heat path through the mounting screws. This strategy allows the system to leverage the mechanical benefits of PLA+ while ensuring thermal stability during operation.

\subsection{Optical Component Sizing and Scope}

To ensure the full angular scan range is achieved without beam clipping (vignetting), the minimum required dimensions for the mirrors were calculated. These calculations are based on the system's geometry and do not extend to lens design, beam focusing, or power density analysis; the optical design is confined to the geometric Line-of-Sight (LOS) stabilization.

\subsubsection{Definitions}
\begin{itemize}
\item \(D_{beam}\): The diameter of the incoming laser beam at the first mirror.
\item \(e\): The inter-mirror pivot distance, obtained from the CAD model.
\item \(\theta_{y,mech}\): The maximum mechanical rotation angle of the X-mirror.
\item \(\alpha_{inc}\): The angle of incidence of the beam on the mirrors (typically 45°).
\item \(S_m\): A safety margin factor (e.g., 1.2 for a 20\% margin).
\end{itemize}

\subsubsection{X-Mirror (First Mirror) Dimensions}
The X-mirror must intercept the stationary incoming beam. The beam's circular cross-section projects as an ellipse onto the tilted mirror surface.
\begin{align}
W_x &= S_m \cdot D_{beam} \\
L_x &= S_m \cdot (D_{beam} / \cos(\alpha_{inc}))
\end{align}
Where \(W_x\) is the minimum width and \(L_x\) is the minimum length.

\subsubsection{Y-Mirror (Second Mirror) Dimensions}
The Y-mirror is more complex as it must intercept a beam that is already being scanned by the X-mirror. Its dimensions must account for the beam's footprint plus the full length of the scanned line.
\begin{align}
W_y &= S_m \cdot \left[ (D_{beam} / \cos(\alpha_{inc})) + (2 \cdot e \cdot \tan(\theta_{y,mech})) \right] \\
L_y &= S_m \cdot (D_{beam} / \cos(\alpha_{inc}))
\end{align}
Where \(W_y\) is the minimum width (along its pivot axis) and \(L_y\) is the minimum length. The length \(L_y\) is determined by the beam footprint, as the primary scan occurs along the width \(W_y\). A more rigorous model would include second-order effects on \(L_y\), but for small angles, they are negligible.

These calculations provide the minimum required clear aperture for the optical elements, guiding the selection and fabrication of the mirrors from HDD platter stock.

\subsection{Optical Component Sizing for Maximum Scan Range}

A critical aspect of the mechanical design is the determination of the minimum required mirror dimensions to prevent beam clipping (vignetting) across the full operational range of the actuators. An insufficient mirror size would act as a mechanical aperture, limiting the achievable scan field. The following analysis calculates the minimum required clear aperture for both the X and Y-axis mirrors based on the system's specified geometry and maximum angular deflection.

\subsubsection{System Parameters and Definitions}
The calculations are based on the following system parameters, derived from component datasheets, the CAD model, and the project's operational requirements:

\begin{itemize}
\item \textbf{Actuator Mechanical Range (\(\theta_{mech,max}\))}: The VCM actuators have a total mechanical range of 30°, corresponding to a maximum deflection from the center position of \(\pm 15^\circ\). Therefore, \(\theta_{mech,max} = 15^\circ\).
\item \textbf{Laser Beam Diameter (\(D_{beam}\))}: The laser module produces a beam with an approximate diameter of 2.0 mm.
\item \textbf{Inter-Mirror Pivot Distance (\(e\))}: The distance between the X-mirror and Y-mirror pivot axes, as determined from the CAD assembly, is 15.0 mm.
\item \textbf{Angle of Incidence (\(\alpha_{inc}\))}: For a standard orthogonal layout, the beam angle of incidence on each mirror surface is 45°.
\item \textbf{Safety Margin (\(S_m\))}: A safety margin of 1.2 (20\%) is applied to all calculations to account for minor misalignments and beam divergence.
\end{itemize}

\subsubsection{X-Mirror (First Mirror) Dimension Calculation}
The first mirror must be large enough to intercept the stationary incoming beam. The beam's circular cross-section of diameter \(D_{beam}\) projects as an ellipse onto the mirror surface, which is tilted at \(\alpha_{inc}\).

The minimum required width (\(W_x\)) and length (\(L_x\)) are given by:
\begin{align}
W_x &= S_m \cdot D_{beam} \\
L_x &= S_m \cdot (D_{beam} / \cos(\alpha_{inc}))
\end{align}

Substituting the system parameters:
\begin{align}
W_x &= 1.2 \cdot 2.0\,\text{mm} = 2.4\,\text{mm} \\
L_x &= 1.2 \cdot (2.0\,\text{mm} / \cos(45^\circ)) \approx 1.2 \cdot (2.0\,\text{mm} / 0.707) \approx 3.4\,\text{mm}
\end{align}
Therefore, the minimum required clear aperture for the X-mirror is \textbf{2.4 mm x 3.4 mm}.

\subsubsection{Y-Mirror (Second Mirror) Dimension Calculation}
The second mirror is more complex as it must intercept a beam that is already being scanned by the first mirror. Its width must account for both the beam's own footprint and the full linear sweep produced by the X-mirror's rotation.

The minimum required width (\(W_y\)) along its pivot axis is given by:
\begin{equation}
W_y = S_m \cdot \left[ (D_{beam} / \cos(\alpha_{inc})) + (2 \cdot e \cdot \tan(\theta_{y,mech,max})) \right]
\end{equation}
The minimum required length (\(L_y\)) is determined by the beam footprint, as the primary scan occurs along the width:
\begin{equation}
L_y = S_m \cdot (D_{beam} / \cos(\alpha_{inc}))
\end{equation}

Substituting the system parameters into the equation for the critical width \(W_y\):
\begin{align}
W_y &= 1.2 \cdot \left[ (2.0\,\text{mm} / \cos(45^\circ)) + (2 \cdot 15.0\,\text{mm} \cdot \tan(15^\circ)) \right] \\
W_y &= 1.2 \cdot [ 2.83\,\text{mm} + (30.0\,\text{mm} \cdot 0.2679) ] \\
W_y &= 1.2 \cdot [ 2.83\,\text{mm} + 8.04\,\text{mm} ] = 1.2 \cdot [10.87\,\text{mm}] \approx 13.04\,\text{mm}
\end{align}
The length calculation remains the same: \(L_y \approx 3.4\,\text{mm}\).

Therefore, the minimum required clear aperture for the Y-mirror is \textbf{13.1 mm x 3.4 mm}. These dimensions will be used for the fabrication of the mirrors from HDD platter stock to ensure the system can achieve its maximum theoretical scan range without vignetting.

\subsubsection{Maximum Scan Field Calculation}
The maximum scan field is determined by the maximum optical deflection angle, which is a direct consequence of the actuator's mechanical range due to the 2\(\theta\) rule.

\begin{equation}
\theta_{opt,max} = 2 \cdot \theta_{mech,max} = 2 \cdot 15^\circ = 30^\circ
\end{equation}

The maximum linear displacement (\(X_{max}\)) from the center of the screen along a single axis is given by the planar projection formula:
\begin{equation}
X_{max} = d \cdot \tan(\theta_{opt,max})
\end{equation}

Substituting the system parameters:
\begin{align}
X_{max} &= 500\,\text{mm} \cdot \tan(30^\circ) \\
X_{max} &\approx 500\,\text{mm} \cdot 0.57735 \approx 288.7\,\text{mm}
\end{align}

The total width of the scan field is twice this maximum displacement. This results in a theoretical maximum scan area at the 50 cm projection distance of approximately \textbf{57.7 cm x 57.7 cm}. This large field of view confirms that the VCM actuators provide a sufficient angular range for a wide variety of applications.

\newpage
% ===================================================================
% CHAPTER 3: SYSTEM DYNAMICS AND CONTROL
% ===================================================================
\section{System Dynamics and Control}

While the kinematic model describes the geometry of the laser steering system, the dynamic model describes its behavior over time in response to inputs. For high-performance control, especially for disturbance rejection, it is advantageous to move beyond simple transfer functions and describe the system's internal dynamics using a state-space representation.

\subsection{State-Space Representation}

State-space modeling provides a complete description of a system's internal state in a first-order matrix form. This representation is powerful for multi-input, multi-output (MIMO) systems and is the foundation for modern control techniques like LQR and state estimators like the Kalman filter.

The standard form is given by two equations:
\begin{align}
    \dot{\mathbf{x}}(t) &= \mathbf{A}\mathbf{x}(t) + \mathbf{B}\mathbf{u}(t) \label{eq:state_equation} \\
    \mathbf{y}(t) &= \mathbf{C}\mathbf{x}(t) + \mathbf{D}\mathbf{u}(t) \label{eq:output_equation}
\end{align}

Where:
\begin{itemize}
    \item \(\mathbf{x}(t)\) is the \textbf{state vector}. This is the minimal set of variables needed to fully describe the system's internal state at time \(t\). For a single mechanical axis (one motor), this vector typically includes angular position (\(\theta\)) and angular velocity (\(\dot{\theta}\)).
    \begin{equation*}
        \mathbf{x} = \begin{bmatrix} \theta \\ \dot{\theta} \end{bmatrix}
    \end{equation*}

    \item \(\mathbf{u}(t)\) is the \textbf{input vector}. This represents the external signal used to control the system. In our case, this is the voltage applied to the motor driver.

    \item \(\mathbf{y}(t)\) is the \textbf{output vector}. This represents the signals that can be physically measured by sensors.

    \item \(\mathbf{A}\) is the \textbf{state matrix}. It describes the system's internal dynamics (how the state evolves on its own, without any input). For a 2x2 matrix, it relates position and velocity.

    \item \(\mathbf{B}\) is the \textbf{input matrix}. It describes how the input signal influences the state (e.g., how input voltage creates an angular acceleration).

    \item \(\mathbf{C}\) is the \textbf{output matrix}. It describes which parts of the state vector are directly measured to form the output vector \(\mathbf{y}\).

    \item \(\mathbf{D}\) is the \textbf{feedthrough matrix}. It represents any direct connection from the input to the output. For most mechanical systems, this is a zero matrix.
\end{itemize}

The matrices \(\mathbf{A}\), \(\mathbf{B}\), and \(\mathbf{C}\) contain the physics of the system. While they can be derived from first principles, a more practical approach for a complex assembly is to determine them experimentally through a process called \textbf{system identification}.

\subsection{Controllability}
Before designing a controller, we must answer a fundamental question: is the system controllable? Controllability asks: "Is it physically possible to drive the system from any initial state to any desired final state in a finite amount of time using the input signal \(\mathbf{u}\)?"

Mathematically, a linear time-invariant (LTI) system is controllable if and only if the \textbf{controllability matrix}, \(\mathcal{C}\), has full rank. For our second-order system, the matrix is:
\begin{equation}
    \mathcal{C} = \begin{bmatrix} \mathbf{B} & \mathbf{AB} \end{bmatrix}
\end{equation}
If \(\det(\mathcal{C}) \neq 0\), the system is controllable, and we can proceed with designing a controller that can fully manipulate its state.

\subsection{Observability}
The dual concept to controllability is observability. It asks: "By observing the output \(\mathbf{y}\) over a period of time, can we uniquely determine the initial state \(\mathbf{x}(0)\)?" In essence, can we deduce the full internal state of the system by looking at its sensor outputs?

Observability is a prerequisite for state estimation. A system is observable if and only if the \textbf{observability matrix}, \(\mathcal{O}\), has full rank. The observability matrix is constructed as:
\begin{equation}
    \mathcal{O} = \begin{bmatrix} \mathbf{C} \\ \mathbf{CA} \end{bmatrix}
\end{equation}
If \(\det(\mathcal{O}) \neq 0\), the system is observable. This means we can design a state estimator, like a Kalman filter, to reconstruct the full state vector (e.g., estimate velocity from position measurements).

\subsection{The Control Workflow: A Full Picture}
The state-space model, along with the concepts of controllability and observability, forms a powerful and cohesive workflow for system control:
\begin{enumerate}
    \item Perform \textbf{System Identification} on the physical hardware to obtain the matrices \(\mathbf{A}\), \(\mathbf{B}\), and \(\mathbf{C}\) that mathematically describe the galvanometer dynamics.
    \item Check the \textbf{controllability} and \textbf{observability} matrices to prove that the system is well-designed and that a state-feedback controller and estimator are feasible.
    \item Implement a \textbf{Kalman Filter} using the system model (\(\mathbf{A, B, C}\)) to produce an optimal estimate of the full state \(\mathbf{x}\) (position and velocity) from noisy sensor data.
    \item Feed this clean state estimate into a state-feedback controller (like an \textbf{LQR controller}) that uses the state matrices to calculate the optimal motor voltage required to drive the system to its target state.
    \item This entire low-level control loop receives its high-level goals (the desired mirror angles \(\theta_x, \theta_y\)) from the numerical \textbf{Inverse Kinematics solver}.
\end{enumerate}

\newpage

% ===================================================================
% CHAPTER 4: OBJECTIVES AND METHODOLOGY
% ===================================================================
\section{Project Objectives}

The primary goal of this research is to design, build, and validate a low-cost, high-performance laser steering system capable of precise targeting and active vibration compensation on mobile platforms. The specific objectives are as follows:

\begin{enumerate}
    \item \textbf{Design and Fabricate a Low-Cost Actuation System:} Develop and construct a functional, dual-axis laser steering system using salvaged mechatronic components (e.g., voice coil motors from HDDs) as a resource-constrained alternative to expensive commercial galvanometers.

    \item \textbf{Develop a Hybrid Sensor Fusion Framework:} Integrate data from an Inertial Measurement Unit (IMU) with vision-based data (optical flow and object tracking) to create a robust, real-time estimate of both platform motion and target location, enabling line-of-sight stabilization.

    \item \textbf{Implement and Compare Advanced Control Strategies:} Derive an accurate state-space model of the system's dynamics via experimental system identification. Based on this model, implement and comparatively analyze the performance of multiple control architectures (PID, LQR, MPC) for stabilization and disturbance rejection.

    \item \textbf{Develop an AI-Powered Visual Servoing Pipeline:} Implement a complete computer vision pipeline for real-time weed detection (YOLOv8), classification, and object tracking (DeepSORT/ByteTrack) to provide dynamic target coordinates to the control system.

    \item \textbf{Experimentally Validate System Performance:} Quantify the system's targeting and stabilization performance under simulated real-world conditions. This involves deploying the system on a motion platform to measure key metrics such as jitter suppression, tracking error, and response time under various dynamic loads.
\end{enumerate}

\section{Proposed Methodology}

The project will be executed in four distinct stages, progressing from hardware fabrication to system-level validation.

\subsection{Stage 1: System Design and Fabrication}
This stage focuses on creating the core physical hardware.
\begin{itemize}
    \item \textbf{Mechanical Design:} A dual-axis galvanometer assembly will be designed using CAD software. The design will focus on optimizing actuation geometry and structural layout to minimize backlash, inertia, and mechanical resonance.
    \item \textbf{Actuator and Optics Sourcing:} Voice coil motors (VCMs) and front-surface mirrors will be salvaged from defunct Hard-Disk Drives (HDDs) or optical disc drives.
    \item \textbf{Electronics Integration:} The mechanical assembly will be integrated with a high-speed microcontroller (e.g., Teensy 4.1), custom motor drivers, an Inertial Measurement Unit (IMU), and an optical flow sensor to form the mechatronic base.
\end{itemize}

\subsection{Stage 2: Modeling and Control System Implementation}
This stage focuses on developing the low-level control intelligence.
\begin{itemize}
    \item \textbf{System Identification:} The dynamic response of the fabricated plant will be characterized. Experimental tests such as step response analysis and frequency sweeps (generating Bode plots) will be performed to gather empirical data.
    \item \textbf{State-Space Modeling:} The empirical data will be used to derive a mathematical state-space model (\(\mathbf{A, B, C}\) matrices) that accurately represents the system's input-output dynamics.
    \item \textbf{Controller Design:} Multiple controllers will be designed and implemented for line-of-sight stabilization based on the identified model, including a classical PID controller and modern state-feedback controllers such as a Linear-Quadratic Regulator (LQR).
\end{itemize}

\subsection{Stage 3: Vision and Sensor Fusion Development}
This stage builds the high-level perception and targeting system.
\begin{itemize}
    \item \textbf{AI-Based Object Detection:} A YOLOv8 model will be trained or fine-tuned on public datasets for robust weed detection.
    \item \textbf{Real-Time Object Tracking:} A tracking algorithm (e.g., DeepSORT or ByteTrack) will be implemented to maintain a persistent identity for each detected target across video frames.
    \item \textbf{Visual-Inertial Fusion:} Algorithms will be developed to fuse the high-frequency motion data from the IMU with the vision-based data (target location, optical flow) to produce a highly accurate, real-time estimate of beam deviation and absolute target location, even during platform motion.
\end{itemize}

\subsection{Stage 4: Experimental Validation and Analysis}
The final stage focuses on testing the integrated system.
\begin{itemize}
    \item \textbf{Testbed Setup:} The complete system will be mounted on a programmable motion platform capable of simulating real-world vibrations and field disturbances.
    \item \textbf{Performance Measurement:} Systematic experiments will be conducted to quantify key performance metrics, including pointing accuracy, tracking error, jitter suppression, and settling time.
    \item \textbf{Comparative Analysis:} The performance and robustness of the different control strategies (PID vs. LQR) will be evaluated and compared under various simulated visual and mechanical workloads.
\end{itemize}

\newpage

\end{document}

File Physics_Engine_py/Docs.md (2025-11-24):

SPECTRA/
├── config/                 <-- DON'T HARDCODE CONSTANTS. Put YAML/JSON configs here.
│   ├── sim_config.yaml
│   └── hardware_params.yaml
├── scripts/
│   └── run_sim.py          <-- Entry point.
├── src/                    <-- Use a src layout to prevent import errors.
│   └── scanner_sim/        <-- The actual package.
│       ├── __init__.py
│       ├── core/
│       │   ├── __init__.py
│       │   ├── plant.py    <-- Abstract Base Class for the system (Sim vs HW).
│       │   ├── physics.py  <-- The differential equations (State Space models).
│       │   └── kinematics.py <-- Coordinate transforms (World -> Galvo -> Screen).
│       ├── control/
│       │   ├── __init__.py
│       │   ├── pid.py      <-- Simple controller for POC.
│       │   ├── lqr.py      <-- Advanced controller.
│       │   └── signals.py  <-- Waveform generators (Sine, Step, Raster).
│       ├── simulation/
│       │   ├── __init__.py
│       │   ├── loop.py     <-- The fixed-time-step integrator.
│       │   └── sensors.py  <-- Noise models and sensor discretization.
│       └── viz/
│           ├── __init__.py
│           ├── viewer.py   <-- OpenGL/PyQtGraph window.
│           └── render.py   <-- Separate the "what" from the "how".
├── tests/
├── requirements.txt
└── setup.py

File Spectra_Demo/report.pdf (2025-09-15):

# TOP SECRET // FOR INTERNAL USE ONLY

## CLASSIFICATION NOTICE

This document contains proprietary and confidential information pertaining to advanced research and development. The information is the exclusive property of the project lead and associated institution.

Unauthorized access, reproduction, distribution, or disclosure of this material, in whole or in part, is strictly prohibited. Violators will be subject to the fullest extent of applicable institutional and civil policies.

STUDENT NAME: | S. HARI PREETHAM
SUPERVISING AUTHORITY: DR. A. CHENNAKESAVA REDDY
INSTITUTION: | JNTUH UCESTH

### Handle with extreme care. Information contained herein is critical to

ongoing research objectives.

CONFIDENTIAL

## A Project Report on

# Real-Time Precision Actuation in Laser Steering Systems via Visual-Inertial Fusion and Active Vibration Compensation

### Submitted by:

## S HARI PREETHAM

21011P0329

### Under the Esteemed Guidance of

## DR. A. CHENNAKESAVA REDDY

### Senior Professor, Department of Mechanical Engineering

## JAWAHARLAL NEHRU TECHNOLOGICAL UNIVERSITY HYDERABAD

### UNIVERSITY COLLEGE OF ENGINEERING SCIENCE AND TECHNOLOGY, HYDERABAD

### August 2025

## Contents

1 Theoretical Framework | 3
2 Mechanical Design and System Architecture | 10
3 System Dynamics and Control | 19
4 Project Objectives | 21
5 Proposed Methodology | 21

i

## Abstract

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

## Problem Statement and Motivation

The deployment of precision laser systems on mobile platforms is severely hampered by several key challenges that current solutions fail to adequately address:
- Prohibitive Cost and Bulk: Existing laser steering platforms depend on highend, laboratory-grade galvanometers or heavy, complex gimbal mechanisms. These systems are expensive, bulky, and unsuitable for lightweight, cost-sensitive mobile applications like agricultural robots.
- Unaddressed Mechanical Disturbance: The majority of existing systems are designed for stationary or mechanically isolated platforms. The critical problem of maintaining real-time pointing accuracy under dynamic disturbances (e.g., vehicle vibration, terrain-induced movement) remains largely under-explored.
- Lack of Sensor Fusion for Beam Control: While sensor fusion is ubiquitous in navigation and robotics, its specific application to real-time beam steering and actuation control is a nascent field. There is a significant gap in integrating visual and inertial data to directly compensate for beam deviation.
- Absence of Real-World Performance Metrics: The literature lacks systematic experimental evaluation of actuation accuracy under vibration. Key performance metrics such as jitter suppression, settling time, and overshoot on disturbed platforms are not well-studied, making it difficult to compare system efficacy.

## Novelty and Contribution

This project makes several novel contributions to the field of mechatronics and control systems:

- Resource-Constrained Mechatronics: It demonstrates that low-cost, salvaged hardware from e-waste can achieve high-precision control performance when coupled with modern software techniques, offering a viable alternative to expensive off-theshelf components.
- Hybrid AI + Control Stack: It pioneers the integration of deep-learning-based computer vision with classical and modern control theory (PID, LQR, MPC) for active visual servoing in a precision actuation context.
- Visual-Inertial Fusion for Disturbance Rejection: It applies cutting-edge mapping and localization concepts (Visual-Inertial SLAM) not for navigation, but as a core component of a disturbance rejection framework for a dynamic targeting system.
- Broad Impact Framework: The core disturbance rejection and active stabilization framework is domain-agnostic and directly applicable to other high-stakes fields, including aerospace (satellite laser communication), defense (target tracking, counter-UAV systems), and medical optics.

## 1 Theoretical Framework

The ability to precisely and rapidly steer a laser beam requires a robust mathematical model of the system’s mechanics and optics. This section develops this framework, beginning with the fundamental laws of reflection and culminating in the kinematic models that translate desired target coordinates into physical actuator commands.

### 1.1 Principle of Reflection and the 2θ Rule

The kinematic model is built upon the law of reflection. A critical and direct consequence for dynamic systems is the 2θ Rule: a mechanical rotation of a mirror by an angle θ deflects the reflected optical path by 2θ.
This angular amplification is a direct result of the geometry. When the mirror plane rotates by θ, the mirror’s normal vector must also rotate by the same angle θ. This rotation changes the angle of incidence by θ. To satisfy the law of reflection with respect to this new normal, the angle of reflection must also change by θ. The total deflection is the sum of these two changes, resulting in a robust and predictable deflection of precisely 2θ. This effect provides a crucial mechanical advantage, allowing small, high-speed rotations to produce a large angular sweep of the laser beam.

### 1.1.1 A First Approximation: Planar Projection

As a first-order model for a single-axis scanner, we can directly apply the 2θ rule using basic trigonometry. Consider a single mirror pivoting at the origin and deflecting a laser beam onto a flat screen positioned at a perpendicular distance d.
The optical deflection angle is 2θ. In the right-angled triangle formed by the pivot point, the center of the screen, and the laser spot, the displacement of the spot (x) is the side opposite to this angle. Therefore, the relationship is given by:

tan(2θ) = opposite
adjacent =

x
d

(1)

Solving for the displacement x gives our first approximation:

x = d tan(2θ) | (2)

While simple and useful for basic estimations, this model is insufficient for a high-fidelity 2D system because it fails to account for the sequential reflections and the physical distance between the two mirrors. For a rigorous model, we must therefore use the vector form of reflection.


Figure 1: Geometric illustration of the principle of reflection and the 2θ rule.

Therefore, by using a dual-axis galvanometer setup, the laser beam can be directed to any point within a defined area on the X–Y plane. The size of this area is determined by the mirror dimensions, the angular range of rotation, and the distance between the mirror system and the projection surface.

### 1.1.2 Vector Form of Reflection

Let V⃗ be the unit vector representing the direction of the incoming laser beam, and let N⃗ be the unit normal vector of the mirror surface. The resulting reflected vector, R⃗ , is given by:
R⃗ = V⃗ − 2(V⃗ · N⃗ )N⃗ | (3)

This equation forms the basis of our kinematic model.

### 1.2 Forward Kinematics: From Mirror Angles to Screen Coordinates

Forward kinematics provides a mathematical model to calculate the final laser spot position on the screen, (Xf , Yf ), from a given set of mechanical mirror angles, (θx, θy). To construct this model, we first define a standard 3D Cartesian coordinate system:

- The origin, [0, 0, 0], is defined as the pivot center of the first mirror (the X-mirror).
- The Z-axis represents the path of the incoming laser beam.
- The X-mirror is responsible for horizontal deflection. It pivots around the Y-axis by a mechanical angle θy.

- The Y-mirror is responsible for vertical deflection. It is positioned at a distance e along the X-axis from the first mirror. It pivots around an axis parallel to the X-axis by a mechanical angle θx.

The initial state is an incoming laser beam traveling along the Z-axis, represented by the vector V⃗
in = [0, 0, 1]T

. The undeflected normals of the mirrors, N⃗

x0 and N⃗
y0, are
typically oriented at 45 degrees to the Z-axis to correctly fold the optical path.
A rotation of a mirror changes its normal vector. The new normal is found by applying a 3D rotation matrix to the initial normal vector.
- Rotation around X-axis (for Y-mirror, angle θx):

Rx(θx) =

1 | 0 | 0
0 cos θx | − sin θx
0 sin θx | cos θx
- (4)
- Rotation around Y-axis (for X-mirror, angle θy):

Ry(θy) =

cos θy | 0 sin θy
0 | 1 | 0
− sin θy | 0 cos θy
- (5)

### 1.2.1 Full Path Algorithm

The final direction of the laser beam is calculated through a sequence of two reflections:

1. First Reflection (X-mirror): The X-mirror’s normal vector is updated based on its rotation: N⃗

x = Ry(θy)N⃗
x0. The incoming beam reflects off this surface, resulting in a new direction vector: R⃗

1 = V⃗

in −2(V⃗

in ·N⃗

x)N⃗

x. The components of R⃗
1 are now
trigonometric functions of the angle θy.
2. Second Reflection (Y-mirror): The Y-mirror’s normal vector is similarly updated: N⃗

y = Rx(θx)N⃗

y0. The beam from the first mirror, R⃗ 1, is the incoming vector
for this reflection. The final direction vector is therefore: R⃗

f inal = R⃗

1−2(R⃗

1 ·N⃗

y)N⃗
y.

It is critical to note that during this second reflection, the dot product term (R⃗

1 · N⃗
y)
mathematically entangles the two rotation angles. Because R⃗

1 is a function of θy and N⃗
y
is a function of θx, the resulting vector R⃗
f inal contains complex, non-linear cross-coupled terms, making it impossible to separate the influence of each angle cleanly.

### 1.2.2 Ray-Plane Intersection and Pincushion Distortion

With the final direction vector R⃗
f inal = [Rx, Ry, Rz]

T
, we can determine its intersection with a screen plane. The final ray originates from the pivot point of the Y-mirror, which is located at P⃗
y = [e, 0, 0]T

. The parametric equation for this ray is P⃗ (t) = P⃗

y + t· R⃗
f inal.
The screen is a plane defined by the equation z = d, where d is the perpendicular distance from the Y-mirror’s pivot axis to the screen. To find the intersection point, we solve the z-component of the parametric equation for the parameter t:

0 + t · Rz = d =⇒ t =

d
Rz

(6)

Substituting t back into the x and y components gives the final coordinates (Xf , Yf ):

Xf = e + t · Rx = e + d

Rx
Rz

(7)

Yf = 0 + t · Ry = d

Ry
Rz

(8)

This model fully describes the geometry of the system. It also reveals the source of pincushion distortion. The final X-coordinate depends not just on its own angle but also on the path length to the screen. This path length is modulated by the tilt of the Y-mirror, causing the scan field to become wider at the top and bottom edges, which creates the characteristic pincushion shape.

### 1.2.3 Matrix Representation of the Kinematic Chain

To more clearly illustrate the coupling between the mirror rotations, we can represent the reflection operation itself as a matrix transformation. For a given mirror normal N⃗ , the reflection matrix Mref (N⃗ ) that transforms an incoming vector V⃗ to a reflected vector R⃗ is given by:

Mref (N⃗ ) = I − 2(N⃗ ⊗ N⃗ ) =

1 − 2N²
x | −2NxNy | −2NxNz
−2NxNy | 1 − 2N²
| y | −2NyNz
−2NxNz | −2NyNz | 1 − 2N² z
- (9)

where I is the identity matrix and ⊗ denotes the outer product.
Using this representation, the entire forward kinematic chain can be expressed as a single composite transformation matrix, Mtotal, acting on the initial beam vector:
1. The reflection matrix for the X-mirror, Mref,X, is a function of its normal, N⃗
x,
which in turn depends on the angle θy.
2. The reflection matrix for the Y-mirror, Mref,Y , is a function of its normal, N⃗
y,
which depends on the angle θx.
3. The final direction vector is therefore given by the product of these matrices:

R⃗

f inal = Mref,Y (θx) · Mref,X(θy) · V⃗
in | (10)

This formulation makes the ”entanglement” explicit. The total transformation matrix is the product of two matrices, each dependent on one of the control angles. Because matrix multiplication is not commutative (AB ̸= BA), the final result is a complex function where the influences of θx and θy are thoroughly mixed. This elegantly demonstrates why a simple, separable analytical solution for the inverse kinematics is not possible.

### 1.3 Inverse Kinematics: The Challenge of Target-to-Angle Mapping

For any practical control application, we must solve the inverse problem: given a desired target on the screen (Xtarget, Ytarget), what are the required mirror angles (θx, θy)? This is the inverse kinematics (IK) problem.
The forward kinematic model, while accurate for simulation, is insufficient for real-time control, especially on a mobile platform, because:

- The reference frame is no longer static; the entire scanner assembly, including the mirror pivots and the screen plane, is moving and vibrating relative to the world.
- The system must solve for angles in real-time to track a target, compensating for both the target’s position and the platform’s own motion.
- As demonstrated, the forward mapping (Xf , Yf ) = f(θx, θy) is a complex, non-linear, and coupled function. A direct analytical inversion to find (θx, θy) = f

−1
(Xf , Yf )
is mathematically intractable for a real-time system.

### 1.3.1 Analytical vs. Numerical IK

An analytical solution would provide a direct, closed-form equation, e.g., θx = f(X, Y ). While derivable for highly simplified cases (e.g., assuming perfectly orthogonal, co-located mirrors), such solutions are brittle and fail to account for real-world mechanical realities, rendering them useless for a high-precision system.
A numerical solution iteratively finds the angles. This approach is more robust and can adapt to complex, non-ideal systems, which is essential for our application. We use the Jacobian-based iterative method.

### 1.4 Numerical Solution: The Jacobian Iterative Method

The Jacobian matrix, J, serves as a ”sensitivity map.” It relates infinitesimal changes in the input (mirror angles) to the resulting infinitesimal changes in the output (screen position). It is the matrix of all first-order partial derivatives of the forward kinematics function:
J(θ) = "∂Xf
∂θx

∂Xf
∂θy
∂Yf
∂θx

∂Yf
∂θy
(11)

where θ = [θx, θy]

T
We use this matrix in an iterative algorithm to converge on the correct angles.

### 1.4.1 Iterative Inverse Kinematic Algorithm

1. Initialization (Step 0): Identify the target position P⃗
target = [Xtarget, Ytarget]

T
Start with the current measured angles of the motors, θcurrent.
2. Calculate Current Position (Step 1): Use the forward kinematics model to calculate the current laser position on the screen, P⃗
current, based on θcurrent.
3. Find the Error (Step 2): Calculate the error vector between the target and current position: ⃗e = P⃗

target − P⃗
current.
4. Calculate Jacobian (Step 3): Compute the Jacobian matrix J at the current angle configuration θcurrent.
5. Determine Angle Correction (Step 4): The desired change in angles, ∆θ, can be found by ”inverting” the Jacobian relationship ⃗e ≈ J∆θ. Instead of using a direct and potentially unstable inverse, we use the Jacobian transpose, which is computationally simpler and more stable:

∆θ = αJ

T
⃗e | (12)

Here, α is a small learning rate (a step size) that ensures a stable convergence.

6. Update Guess (Step 5): Update the motor angles: θnew = θcurrent + ∆θ.
7. Repeat: Set θcurrent = θnew and repeat from Step 1 until the magnitude of the error vector ||⃗e|| is below a desired tolerance.

This iterative process allows the system to find the correct angles even for a complex, non-ideal mechanical setup and is the core of the high-level steering control.

### 1.4.2 Limitations of the Jacobian Transpose Method

While computationally efficient, this basic iterative method has a critical flaw for a physical system: it is unconstrained. The algorithm has no inherent knowledge of the galvanometer’s mechanical limits. If a target is commanded near or outside the scanner’s reachable workspace, this algorithm will calculate and command angles (e.g., θx = 15◦ )
that are physically impossible for the actuator to achieve. This can lead to actuator saturation, instability, and unpredictable behavior at the edges of the workspace. For a robust, ”battle-ready” system, we must be able to handle these physical constraints gracefully.

### 1.5 Enhanced Solution: Constrained Optimization

To address the limitations of the unconstrained approach, we re-frame the IK problem as a formal optimization problem. The goal is no longer just to find *any* solution, but to find the *best possible* solution that satisfies all physical constraints. This is achieved by finding the angle vector ⃗θ that minimizes a scalar Cost Function, C(

⃗θ).

### 1.5.1 The Cost Function

The Cost Function mathematically defines the ”total error” of the system, balancing pointing accuracy with adherence to physical limits.

C(

⃗θ) = 1
2

||FK(⃗θ) − P⃗
target||² + βH(
⃗θ, ⃗θmax) | (13)

The function consists of two terms:

- Accuracy Term: 1
2

||FK(⃗θ) − P⃗
target||²
is the squared distance error. Minimizing this term drives the laser to the target.
- Constraint Term: H(

⃗θ, ⃗θmax) is a barrier function that penalizes angles approaching their limits. A logarithmic barrier is used, which approaches infinity as any angle θi nears its limit ±θmax, creating a ”force field” that the optimizer will not violate.

The scalar weight β controls the strength of this barrier.

### 1.5.2 Solution via Gradient Descent

The cost function is minimized using the Gradient Descent algorithm, which iteratively updates the angles by taking steps in the direction opposite to the gradient of the cost function.
⃗θk+1 = ⃗θk − α∇C(
⃗θk) | (14)

The gradient ∇C is derived from Equation 13 and is composed of the gradient of both the accuracy and the barrier terms. The gradient of the accuracy term is found to be J(

⃗θ)
T
- (FK(⃗θ) − P⃗
target).

This constrained optimization framework represents the final, robust solution. It leverages the efficiency of the Jacobian while formally incorporating actuator limits. This ensures that the calculated angles are always physically achievable, providing stable and predictable behavior across the entire workspace and preventing the controller from commanding impossible states. This is the core algorithm for the high-level steering controller.

### 1.5.3 Algorithm Stability and Convergence

The stability of the numerical IK solver is a critical consideration. Unlike an analytical solution, an iterative algorithm’s performance is not guaranteed and depends on its formulation and tuning.
The proposed algorithm incorporates several features to ensure stable and predictable convergence:
- Use of the Jacobian Transpose: The choice of the Jacobian Transpose method, ∆θ = αJ

T⃗e, over a direct matrix inverse, ∆θ = J

−1⃗e, is a key stabilizing factor. The transpose method is less susceptible to issues with matrix singularities (positions where the inverse is undefined) and generally provides a smoother, more stable path towards the solution, even if it sometimes requires more iterations.

- The Learning Rate (α): The scalar step size, α, is a crucial tuning parameter. A small, fixed value for α will be chosen to prevent the algorithm from taking excessively large steps. This prevents overshooting the target and ensures the iterative process does not become unstable or oscillate.
- Constraint Handling: The inclusion of the logarithmic barrier function in the constrained optimization framework is another critical stabilizing feature. By preventing the solver from ever commanding angles outside the known physical limits of the actuator, it eliminates a major source of potential instability and ensures all commanded states are physically achievable.‘

Verification Method: The stability of the implemented algorithm will be verified experimentally. The system will be subjected to a series of step commands to various points within the workspace, including points at the extreme edges. The convergence of the error vector ||⃗e|| over the iterations will be plotted and analyzed. A stable system will demonstrate a smooth, monotonic decrease in error. Any oscillatory or divergent behavior will be addressed by tuning the learning rate α and the barrier weight β.

## 2 Mechanical Design and System Architecture

The efficacy of the laser stabilization and targeting system is fundamentally dependent on the precision, rigidity, and thermal stability of its mechanical architecture. This section details the design of the physical assembly, outlining the system layout, the novel solution for the kinematic mirror mounting, and the rationale behind the material selection and thermal management strategies.

### 2.1 System Layout and Kinematic Mounting

The system is configured as a traditional orthogonal two-axis scanner to produce a Cartesian motion profile. The primary actuators are two Voice Coil Motors (VCMs) salvaged from Hard Disk Drives (HDDs), chosen for their low inertia and high-speed response.

- The X-axis galvanometer assembly is mounted horizontally onto the main system baseplate. Its pivot axis is oriented vertically (Zaxis).
- The Y-axis galvanometer assembly is mounted on a rigid, 90-degree vertical support structure. Its pivot axis is oriented horizontally (Yaxis).

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


(a) X-axis VCM actuator mount


(b) Cross-section area analysis of X-axis mount

Figure 2: X-axis actuator mount and corresponding cross-section analysis.


(a) Y-axis VCM actuator mount


(b) Cross-section area analysis of Y-axis mount

Figure 3: Y-axis actuator mount and corresponding cross-section analysis.


Figure 4: CAD model of the complete dual-axis galvanometer assembly, showing orthogonal arrangement of VCM actuators and kinematic mounting points on the main baseplate.


Figure 5: Structural cross-section area analysis and mating surfaces of the full assembly. The mounts are fastened using M4 nuts, bolts, and washers.

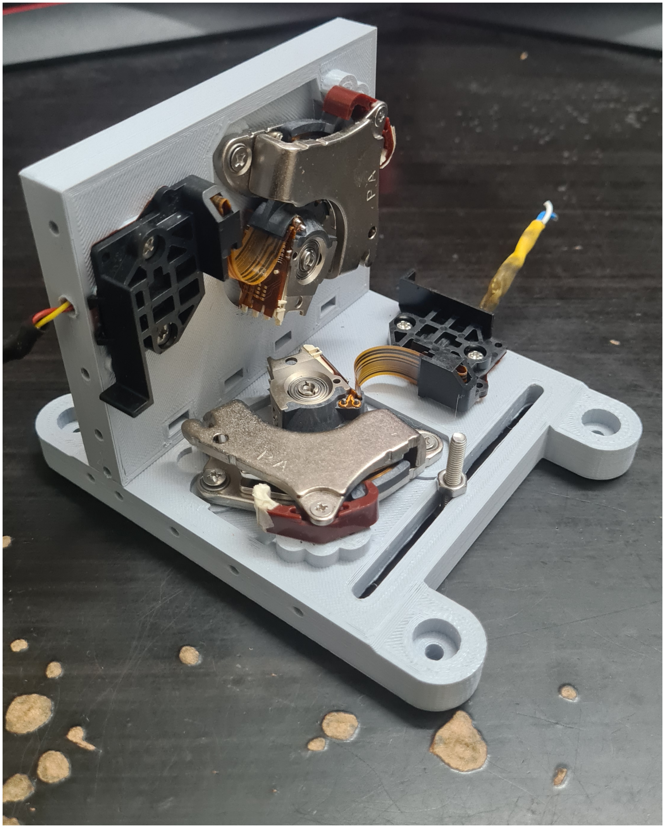
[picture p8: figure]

Figure 6: Photograph of the 3D-printed dual-axis galvanometer assembly.

### 2.2 VCM Mirror Mount: The Decoupled Slotted-Plate Solution

The core of the mechanical design addresses the kinematic mounting paradox, wherein the mirror’s reflective surface must lie on the actuator’s pivot axis, a volume physically occupied by the bearing assembly. To resolve this, a decoupled, slotted-plate mounting system was designed.
This system consists of a stationary plate, fabricated from the chosen polymer, which is mounted to the VCM’s fixed base. A precision slot, with its centerline designed to be perfectly collinear with the VCM’s axis of rotation, provides a rigid, kinematically correct guide for the mirror element. The moving arm of the VCM actuates the mirror via a small, custom-designed fork. This architecture provides superior geometric accuracy and rigidity compared to a cantilevered bracket by separating the function of alignment

(handled by the stationary plate) from the function of actuation (handled by the moving arm).

Figure 7: Detailed view of the custom slotted-plate mirror mount. The stationary plate provides a precise guide for the mirror, ensuring its reflective surface remains on the pivot axis.

### 2.3 Material Selection and Thermal Management Strategy

The selection of the fabrication material involved a critical trade-off analysis between mechanical performance and thermal stability. The primary heat sources are the VCM coils, which can reach elevated temperatures during high-duty cycle operation.

### 2.3.1 Material Choice

A PLA+ (Professional PLA) filament was selected for all 3D printed structural components. This decision prioritizes the material’s superior mechanical properties at ambient temperatures. The higher Young’s Modulus (stiffness) and lower susceptibility to creep under static load compared to other FDM materials like PETG are critical for maintaining the long-term dimensional stability and precision of the kinematic mounts and mirror alignment slots.

### 2.3.2 Thermal Management

To mitigate the risk of thermal deformation associated with PLA+’s low glass transition temperature (approx. 60°C), a thermal break is integrated into the mounting design. The VCM assemblies are mounted via metal standoffs, creating an insulating air gap that minimizes heat transfer to the PLA+ baseplate. Furthermore, thin polyimide (Kapton) tape washers are used at the screw-standoff interfaces. Kapton tape is a high-performance polymer film that serves as both a superior electrical insulator and a robust thermal insulator, effectively blocking the conductive heat path through the mounting screws. This strategy allows the system to leverage the mechanical benefits of PLA+ while ensuring thermal stability during operation.

### 2.4 Optical Component Sizing and Scope

To ensure the full angular scan range is achieved without beam clipping (vignetting), the minimum required dimensions for the mirrors were calculated. These calculations are based on the system’s geometry and do not extend to lens design, beam focusing, or power density analysis; the optical design is confined to the geometric Line-of-Sight (LOS) stabilization.

### 2.4.1 Definitions

- Dbeam: The diameter of the incoming laser beam at the first mirror.
- e: The inter-mirror pivot distance, obtained from the CAD model.
- θy,mech: The maximum mechanical rotation angle of the X-mirror.

- αinc: The angle of incidence of the beam on the mirrors (typically 45°).
- Sm: A safety margin factor (e.g., 1.2 for a 20% margin).

### 2.4.2 X-Mirror (First Mirror) Dimensions

The X-mirror must intercept the stationary incoming beam. The beam’s circular cross-section projects as an ellipse onto the tilted mirror surface.

Wx = Sm · Dbeam | (15)
Lx = Sm · (Dbeam/ cos(αinc)) | (16)

Where Wx is the minimum width and Lx is the minimum length.

### 2.4.3 Y-Mirror (Second Mirror) Dimensions

The Y-mirror is more complex as it must intercept a beam that is already being scanned by the X-mirror. Its dimensions must account for the beam’s footprint plus the full length of the scanned line.

Wy = Sm · [(Dbeam/ cos(αinc)) + (2 · e · tan(θy,mech))] | (17)
Ly = Sm · (Dbeam/ cos(αinc)) | (18)

Where Wy is the minimum width (along its pivot axis) and Ly is the minimum length. The length Ly is determined by the beam footprint, as the primary scan occurs along the width Wy. A more rigorous model would include second-order effects on Ly, but for small angles, they are negligible.
These calculations provide the minimum required clear aperture for the optical elements, guiding the selection and fabrication of the mirrors from HDD platter stock.

### 2.5 Optical Component Sizing for Maximum Scan Range

A critical aspect of the mechanical design is the determination of the minimum required mirror dimensions to prevent beam clipping (vignetting) across the full operational range of the actuators. An insufficient mirror size would act as a mechanical aperture, limiting the achievable scan field. The following analysis calculates the minimum required clear aperture for both the X and Y-axis mirrors based on the system’s specified geometry and maximum angular deflection.

### 2.5.1 System Parameters and Definitions

The calculations are based on the following system parameters, derived from component datasheets, the CAD model, and the project’s operational requirements:

- Actuator Mechanical Range (θmech,max): The VCM actuators have a total mechanical range of 30°, corresponding to a maximum deflection from the center position of ±15◦

. Therefore, θmech,max = 15◦ .

- Laser Beam Diameter (Dbeam): The laser module produces a beam with an approximate diameter of 2.0 mm.

- Inter-Mirror Pivot Distance (e): The distance between the X-mirror and Y-mirror pivot axes, as determined from the CAD assembly, is 15.0 mm.
- Angle of Incidence (αinc): For a standard orthogonal layout, the beam angle of incidence on each mirror surface is 45°.
- Safety Margin (Sm): A safety margin of 1.2 (20%) is applied to all calculations to account for minor misalignments and beam divergence.

### 2.5.2 X-Mirror (First Mirror) Dimension Calculation

The first mirror must be large enough to intercept the stationary incoming beam. The beam’s circular cross-section of diameter Dbeam projects as an ellipse onto the mirror surface, which is tilted at αinc.
The minimum required width (Wx) and length (Lx) are given by:
Wx = Sm · Dbeam | (19)
Lx = Sm · (Dbeam/ cos(αinc)) | (20)

Substituting the system parameters:

Wx = 1.2 · 2.0 mm = 2.4 mm | (21)
Lx = 1.2 · (2.0 mm/ cos(45◦
)) ≈ 1.2 · (2.0 mm/0.707) ≈ 3.4 mm | (22)

Therefore, the minimum required clear aperture for the X-mirror is 2.4 mm x 3.4 mm.

### 2.5.3 Y-Mirror (Second Mirror) Dimension Calculation

The second mirror is more complex as it must intercept a beam that is already being scanned by the first mirror. Its width must account for both the beam’s own footprint and the full linear sweep produced by the X-mirror’s rotation.
The minimum required width (Wy) along its pivot axis is given by:
Wy = Sm · [(Dbeam/ cos(αinc)) + (2 · e · tan(θy,mech,max))] | (23)

The minimum required length (Ly) is determined by the beam footprint, as the primary scan occurs along the width:

Ly = Sm · (Dbeam/ cos(αinc)) | (24)

Substituting the system parameters into the equation for the critical width Wy:

Wy = 1.2 · [(2.0 mm/ cos(45◦

)) + (2 · 15.0 mm · tan(15◦
))] | (25)
Wy = 1.2 · [2.83 mm + (30.0 mm · 0.2679)] | (26)
Wy = 1.2 · [2.83 mm + 8.04 mm] = 1.2 · [10.87 mm] ≈ 13.04 mm | (27)

The length calculation remains the same: Ly ≈ 3.4 mm.
Therefore, the minimum required clear aperture for the Y-mirror is 13.1 mm x 3.4 mm. These dimensions will be used for the fabrication of the mirrors from HDD platter stock to ensure the system can achieve its maximum theoretical scan range without vignetting.

### 2.5.4 Maximum Scan Field Calculation

The maximum scan field is determined by the maximum optical deflection angle, which is a direct consequence of the actuator’s mechanical range due to the 2θ rule.

θopt,max = 2 · θmech,max = 2 · 15◦ = 30◦
(28)

The maximum linear displacement (Xmax) from the center of the screen along a single axis is given by the planar projection formula:

Xmax = d · tan(θopt,max) | (29)

Substituting the system parameters:

Xmax = 500 mm · tan(30◦
) | (30)
Xmax ≈ 500 mm · 0.57735 ≈ 288.7 mm | (31)

The total width of the scan field is twice this maximum displacement. This results in a theoretical maximum scan area at the 50 cm projection distance of approximately

### 57.7 cm x 57.7 cm. This large field of view confirms that the VCM actuators provide

a sufficient angular range for a wide variety of applications.

## 3 System Dynamics and Control

While the kinematic model describes the geometry of the laser steering system, the dynamic model describes its behavior over time in response to inputs. For high-performance control, especially for disturbance rejection, it is advantageous to move beyond simple transfer functions and describe the system’s internal dynamics using a state-space representation.

### 3.1 State-Space Representation

State-space modeling provides a complete description of a system’s internal state in a first-order matrix form. This representation is powerful for multi-input, multi-output (MIMO) systems and is the foundation for modern control techniques like LQR and state estimators like the Kalman filter.
The standard form is given by two equations:
x˙(t) = Ax(t) + Bu(t) | (32)
y(t) = Cx(t) + Du(t) | (33)

Where:

- x(t) is the state vector. This is the minimal set of variables needed to fully describe the system’s internal state at time t. For a single mechanical axis (one motor), this vector typically includes angular position (θ) and angular velocity ( ˙θ).

x =

θ
˙θ

- u(t) is the input vector. This represents the external signal used to control the system. In our case, this is the voltage applied to the motor driver.
- y(t) is the output vector. This represents the signals that can be physically measured by sensors.
- A is the state matrix. It describes the system’s internal dynamics (how the state evolves on its own, without any input). For a 2x2 matrix, it relates position and velocity.
- B is the input matrix. It describes how the input signal influences the state (e.g., how input voltage creates an angular acceleration).
- C is the output matrix. It describes which parts of the state vector are directly measured to form the output vector y.
- D is the feedthrough matrix. It represents any direct connection from the input to the output. For most mechanical systems, this is a zero matrix.

The matrices A, B, and C contain the physics of the system. While they can be derived from first principles, a more practical approach for a complex assembly is to determine them experimentally through a process called system identification.

### 3.2 Controllability

Before designing a controller, we must answer a fundamental question: is the system controllable? Controllability asks: ”Is it physically possible to drive the system from any initial state to any desired final state in a finite amount of time using the input signal u?”
Mathematically, a linear time-invariant (LTI) system is controllable if and only if the controllability matrix, C, has full rank. For our second-order system, the matrix is:

C =

B AB
(34)

If det(C) ̸= 0, the system is controllable, and we can proceed with designing a controller that can fully manipulate its state.
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

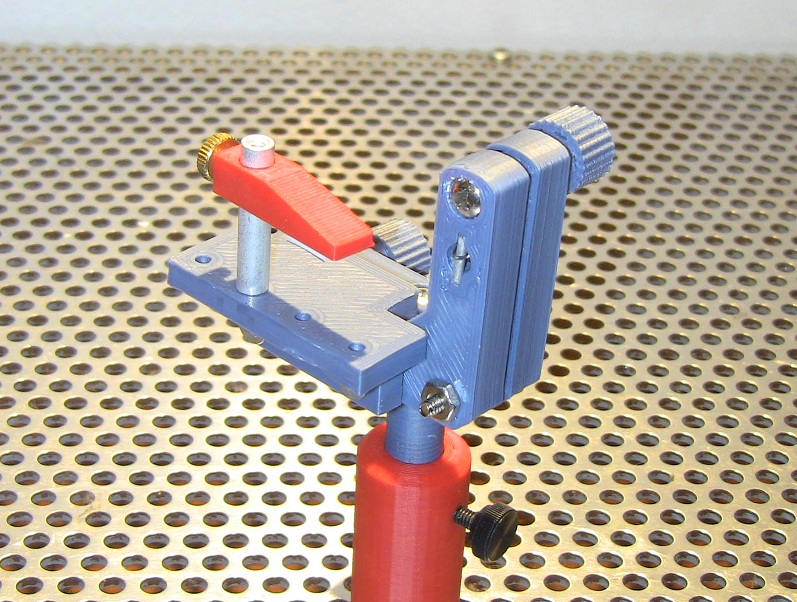
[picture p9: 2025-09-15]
CAD_FILES/Optical mount for lens _ mirror _ prism - 1004337/images/lensmount3.jpg

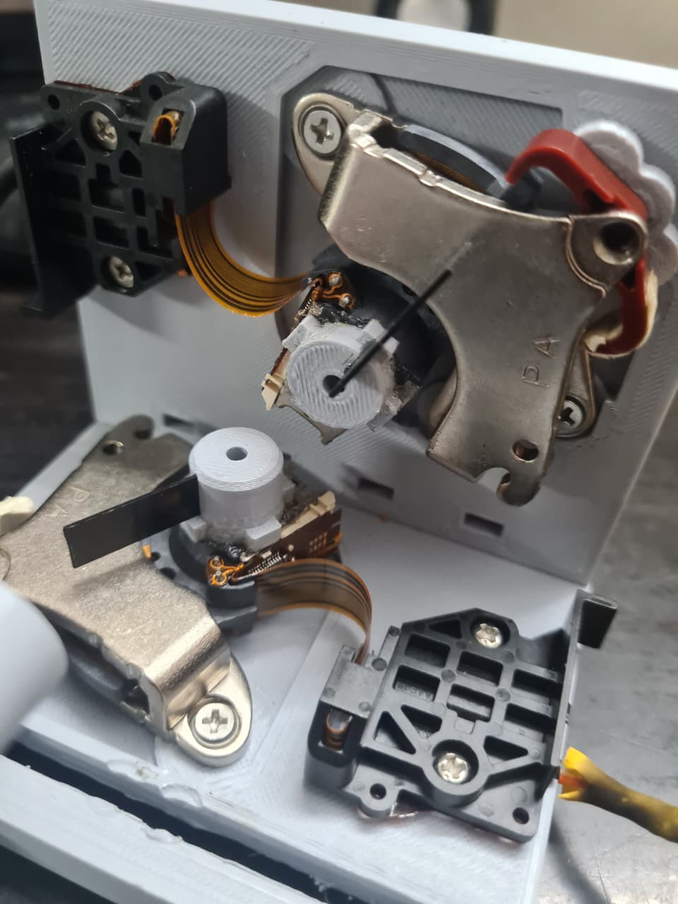
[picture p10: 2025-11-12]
Spectra_Demo/images/WhatsApp Image 2025-10-31 at 4.09.38 AM.jpeg

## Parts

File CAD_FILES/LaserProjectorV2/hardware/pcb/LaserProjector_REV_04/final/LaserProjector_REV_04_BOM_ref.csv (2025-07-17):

Ref | Value | MPN | Manufacturer | Package | Datasheet
C1 | 2.2uF | GRM188R61H225KE11D | Murata Electronics | 0603 | https://datasheet.lcsc.com/lcsc/1912111437_Murata-Electronics-GRM188R61H225KE11D_C162273.pdf
C2 | 22uF | EEEHBH220UAP | Panasonic | SMD (6.3x5.8mm) | https://datasheet.lcsc.com/lcsc/1912111437_PANASONIC-EEEHBH220UAP_C401821.pdf
C3 | 10uF | CL21A106KAYNNNE | Samsung Electro-Mechanics | 0805 | https://datasheet.lcsc.com/szlcsc/1811121310_Samsung-Electro-Mechanics-CL21A106KAYNNNE_C15850.pdf
C4 | 22uF | C2012X5R0J226MT000N | TDK | 0805 | https://datasheet.lcsc.com/szlcsc/1912111437_TDK-C2012X5R0J226MT000N_C329961.pdf
C5 | 1nF | GCM155R71H102KA37D | Murata Electronics | 0402 | https://datasheet.lcsc.com/lcsc/1811081510_Murata-Electronics-GCM155R71H102KA37D_C126532.pdf
C6 | 22nF | GRM155R71E223JA61D | Murata Electronics | 0402 | https://datasheet.lcsc.com/lcsc/1912111437_Murata-Electronics-GRM155R71E223JA61D_C426639.pdf
C7 | 100nF | CC0402KRX7R7BB104 | Yageo | 0402 | https://www.yageo.com/upload/media/product/productsearch/datasheet/mlcc/UPY-GPHC_X7R_6.3V-to-50V_18.pdf
C8 | 2.2uF | GRM188R61H225KE11D | Murata Electronics | 0603 | https://datasheet.lcsc.com/lcsc/1912111437_Murata-Electronics-GRM188R61H225KE11D_C162273.pdf
C9 | 22uF | EEEHBH220UAP | Panasonic | SMD (6.3x5.8mm) | https://datasheet.lcsc.com/lcsc/1912111437_PANASONIC-EEEHBH220UAP_C401821.pdf
C10 | 1nF | GCM155R71H102KA37D | Murata Electronics | 0402 | https://datasheet.lcsc.com/lcsc/1811081510_Murata-Electronics-GCM155R71H102KA37D_C126532.pdf
C11 | 22nF | GRM155R71E223JA61D | Murata Electronics | 0402 | https://datasheet.lcsc.com/lcsc/1912111437_Murata-Electronics-GRM155R71E223JA61D_C426639.pdf
J1 | J_Molex-PicoBlade-4P-P1.25mm | 0530470410 | Molex | Through Hole, P=1.25mm | https://www.molex.com/pdm_docs/sd/530470410_sd.pdf
J2 | JST-XH-B2B | B2B-XH-A(LF)(SN) | JST Sales America | Through Hole, P=2.5mm | http://www.jst-mfg.com/product/pdf/eng/eXH.pdf
J3 | J_Molex-PicoBlade-3P-P1.25mm | 0530470310 | Molex | Through Hole, P=1.25mm | https://www.molex.com/pdm_docs/sd/530470310_sd.pdf
J4 | J_Molex-PicoBlade-3P-P1.25mm | 0530470310 | Molex | Through Hole, P=1.25mm | https://www.molex.com/pdm_docs/sd/530470310_sd.pdf
J5 | JST-XH-B4B | B4B-XH-A(LF)(SN) | JST Sales America | Through Hole, P=2.5mm | https://datasheet.lcsc.com/szlcsc/1811151545_JST-Sales-America-B4B-XH-A-LF-SN_C144395.pdf
J7 | J_Molex-PicoBlade-4P-P1.25mm | 0530470410 | Molex | Through Hole, P=1.25mm | https://www.molex.com/pdm_docs/sd/530470410_sd.pdf
L1 | 2.2uH | VLCF4020T-2R2N1R7 | TDK | 4x4x2mm | https://datasheet.lcsc.com/szlcsc/1810211523_TDK-VLCF4020T-2R2N1R7_C136245.pdf
Q1 | NCE2060K | NCE2060K | Wuxi NCE Power Semiconductor | TO-252-2L | http://www.ncepower.com/Upload/MOSFET/NCE2060Kdatasheet-15115513193.pdf
Q2 | NMOS | NTR4501NT1G | ON Semicon | SOT-23 | https://datasheet.lcsc.com/szlcsc/1810301530_ON-Semicon-NTR4501NT1G_C85416.pdf
R1 | 0.2R | WW25WR200FTL | Walsin Tech Corp | 2512 | https://datasheet.lcsc.com/lcsc/1912211104_Walsin-Tech-Corp-WW25WR200FTL_C470051.pdf
R2 | 47k | RC0402FR-0747KL | Yageo | 0402 | https://www.mouser.dk/datasheet/2/447/PYu_RC_Group_51_RoHS_L_10-1664068.pdf
R3 | 0.2R | WW25WR200FTL | Walsin Tech Corp | 2512 | https://datasheet.lcsc.com/lcsc/1912211104_Walsin-Tech-Corp-WW25WR200FTL_C470051.pdf
R4 | 100k | RT0402BRE07100KL | YAGEO | 0402 | https://datasheet.lcsc.com/lcsc/1810241324_YAGEO-RT0402BRE07100KL_C136979.pdf
R5 | 1k | 0402WGF1001TCE | Uniroyal Elec | 0402 | https://datasheet.lcsc.com/szlcsc/1811132311_Uniroyal-Elec-0402WGF1001TCE_C11702.pdf
R6 | 1k | 0402WGF1001TCE | Uniroyal Elec | 0402 | https://datasheet.lcsc.com/szlcsc/1811132311_Uniroyal-Elec-0402WGF1001TCE_C11702.pdf
R7 | 10k | RT0402BRD0710KL | YAGEO | 0402 | https://datasheet.lcsc.com/szlcsc/1810241334_YAGEO-RT0402BRD0710KL_C190095.pdf
R8 | 10k | RT0402BRD0710KL | YAGEO | 0402 | https://datasheet.lcsc.com/szlcsc/1810241334_YAGEO-RT0402BRD0710KL_C190095.pdf
R9 | 0.2R | WW25WR200FTL | Walsin Tech Corp | 2512 | https://datasheet.lcsc.com/lcsc/1912211104_Walsin-Tech-Corp-WW25WR200FTL_C470051.pdf
R10 | 47k | RC0402FR-0747KL | Yageo | 0402 | https://www.mouser.dk/datasheet/2/447/PYu_RC_Group_51_RoHS_L_10-1664068.pdf
R11 | 0.2R | WW25WR200FTL | Walsin Tech Corp | 2512 | https://datasheet.lcsc.com/lcsc/1912211104_Walsin-Tech-Corp-WW25WR200FTL_C470051.pdf
R12 | 100k | RT0402BRE07100KL | YAGEO | 0402 | https://datasheet.lcsc.com/lcsc/1810241324_YAGEO-RT0402BRE07100KL_C136979.pdf
R13 | 1k | 0402WGF1001TCE | Uniroyal Elec | 0402 | https://datasheet.lcsc.com/szlcsc/1811132311_Uniroyal-Elec-0402WGF1001TCE_C11702.pdf
R14 | 1k | 0402WGF1001TCE | Uniroyal Elec | 0402 | https://datasheet.lcsc.com/szlcsc/1811132311_Uniroyal-Elec-0402WGF1001TCE_C11702.pdf
R15 | 10k | RT0402BRD0710KL | YAGEO | 0402 | https://datasheet.lcsc.com/szlcsc/1810241334_YAGEO-RT0402BRD0710KL_C190095.pdf
SW1 | EVPAA602W | EVPAA602W | Panasonic | SMD | https://datasheet.lcsc.com/szlcsc/1809192044_PANASONIC-EVPAA602W_C79148.pdf
SW2 | EVPAA602W | EVPAA602W | Panasonic | SMD | https://datasheet.lcsc.com/szlcsc/1809192044_PANASONIC-EVPAA602W_C79148.pdf
U1 | TPS62162DSG | TPS62162DSG | Texas Instruments | WSON-8 (2x2mm) | https://datasheet.lcsc.com/lcsc/1806070425_Texas-Instruments-TPS62162DSGR_C40256.pdf
U2 | STSPIN220 | STSPIN220 | STMicroelectronics | VFQFPN 3x3x1.0 | www.st.com/resource/en/datasheet/stspin220.pdf
U3 | STSPIN220 | STSPIN220 | STMicroelectronics | VFQFPN 3x3x1.0 | www.st.com/resource/en/datasheet/stspin220.pdf
U4 | ESP32 |  |  |  | https://www.espressif.com/sites/default/files/documentation/esp32-wroom-32_datasheet_en.pdf

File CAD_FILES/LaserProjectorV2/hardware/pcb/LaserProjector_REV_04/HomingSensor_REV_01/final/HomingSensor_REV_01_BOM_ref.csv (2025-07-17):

Ref | Value | MPN | Manufacturer | Package | Datasheet
C1 | 10nF | CL05B103KB5NNNC | Samsung Electro-Mechanics | 0402 | https://datasheet.lcsc.com/szlcsc/1810191223_Samsung-Electro-Mechanics-CL05B103KB5NNNC_C15195.pdf
R1 | 100R | AC0402FR-07100RL | Yageo | 0402 | https://eu.mouser.com/datasheet/2/447/PYu-AC_51_RoHS_L_7-1714230.pdf
R2 | 220R | 0402WGF2200TCE | UNI-ROYAL | 0402 | https://datasheet.lcsc.com/szlcsc/1811011214_UNI-ROYAL-Uniroyal-Elec-0402WGF2200TCE_C25091.pdf
U1 | QRE1113 |  |  |  | http://www.onsemi.com/pub/Collateral/QRE1113-D.PDF

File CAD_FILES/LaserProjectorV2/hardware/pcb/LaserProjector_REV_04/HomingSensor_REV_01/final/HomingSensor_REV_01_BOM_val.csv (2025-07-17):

Qty | Designator | Value | Datasheet | MPN | Manufacturer | Package
1 | C1 | 10nF | https://datasheet.lcsc.com/szlcsc/1810191223_Samsung-Electro-Mechanics-CL05B103KB5NNNC_C15195.pdf | Samsung Electro-Mechanics | CL05B103KB5NNNC | 0402
1 | R1 | 100R | https://eu.mouser.com/datasheet/2/447/PYu-AC_51_RoHS_L_7-1714230.pdf | Yageo | AC0402FR-07100RL | 0402
1 | R2 | 220R | https://datasheet.lcsc.com/szlcsc/1811011214_UNI-ROYAL-Uniroyal-Elec-0402WGF2200TCE_C25091.pdf | UNI-ROYAL | 0402WGF2200TCE | 0402
1 | U1 | QRE1113 | http://www.onsemi.com/pub/Collateral/QRE1113-D.PDF

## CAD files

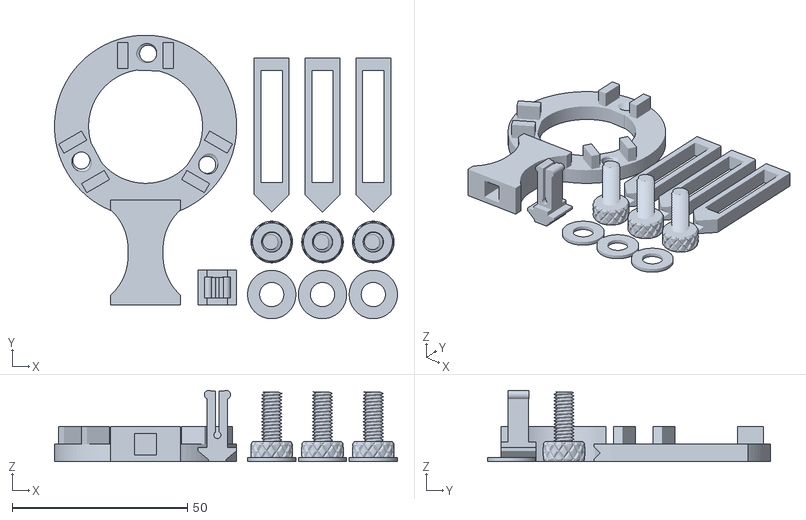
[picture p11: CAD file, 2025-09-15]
CAD_FILES/Optics Bench Lensholder - 2336754/files/complete_set.stl
97.9 x 80.9 x 20.4

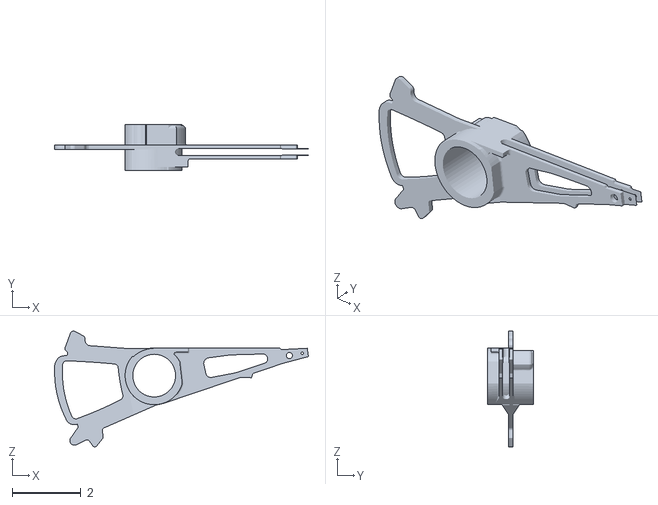
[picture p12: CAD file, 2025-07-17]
CAD_FILES/hard-drive-actuator-arm/ReadHead.stl
7.38 x 1.33 x 3.37

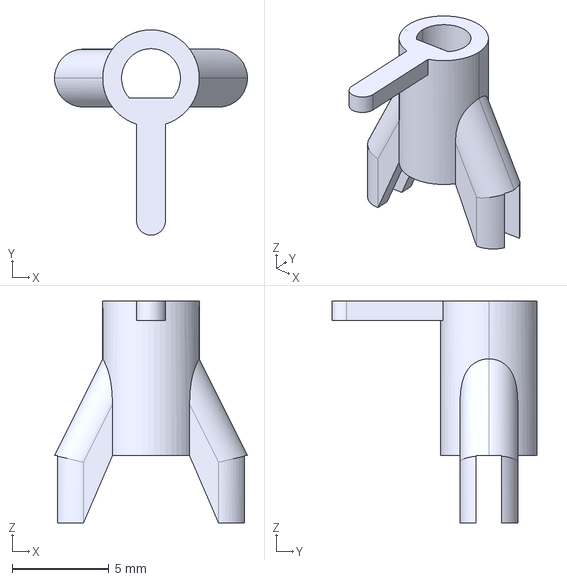
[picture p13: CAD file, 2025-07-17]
CAD_FILES/LaserProjectorV2/hardware/cad/MirrorHolder.STEP
10.0 x 10.6 x 11.5 mm

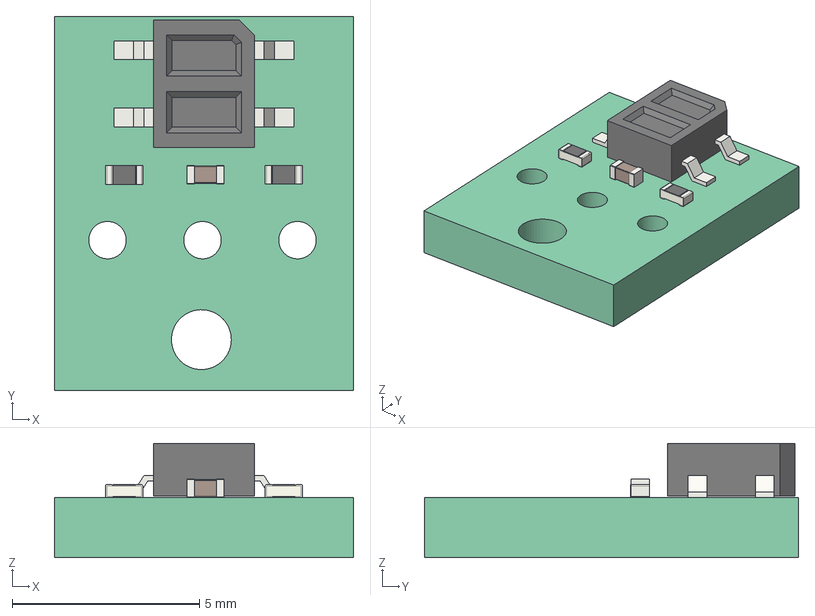
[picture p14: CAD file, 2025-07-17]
CAD_FILES/LaserProjectorV2/hardware/pcb/LaserProjector_REV_04/HomingSensor_REV_01/final/HomingSensor_REV_01.step
8.00 x 10.0 x 3.05 mm
Local_CS_25fb
Pcb_25fb
PCB_Sketch_25fb
U1_OnSemi_CASE100CY_5FA408A3
R2_R_0402_1005Metric_5FA4088F
R1_R_0402_1005Metric_5FA40D70
C1_C_0402_1005Metric_5FA4085A

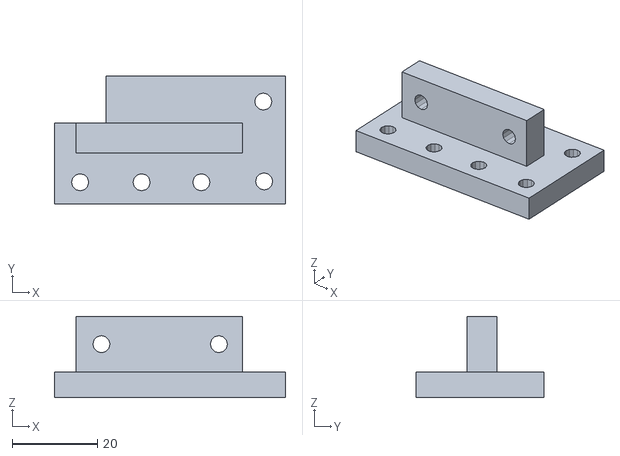
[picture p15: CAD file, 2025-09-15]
CAD_FILES/Optical mount for lens _ mirror _ prism - 1004337/files/lens_mount3_part1.stl
54.1 x 30.0 x 19.0

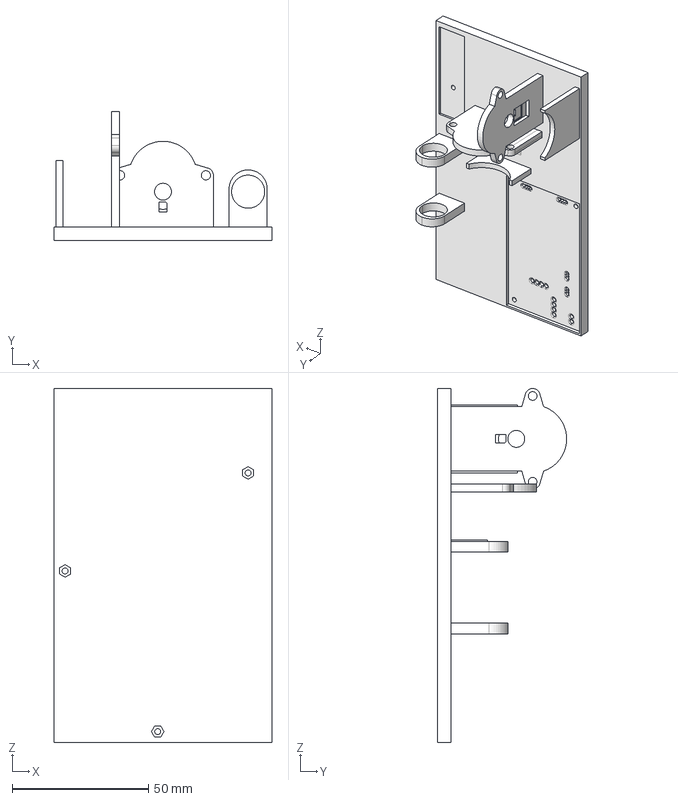
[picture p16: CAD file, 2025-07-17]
CAD_FILES/LaserProjectorV2/hardware/cad/ScannerHolder.STEP
80.0 x 47.5 x 130.0 mm

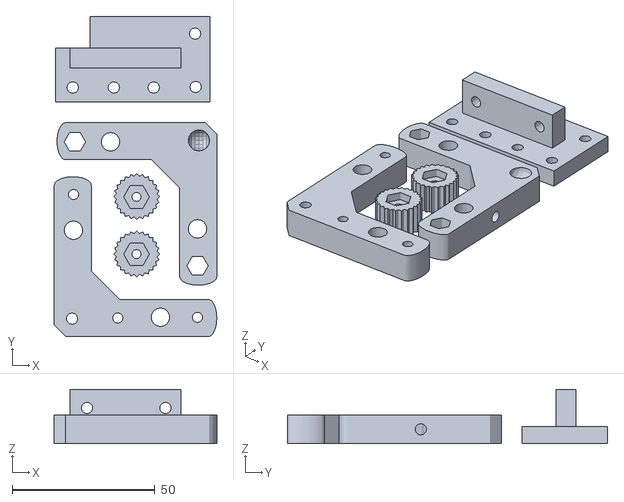
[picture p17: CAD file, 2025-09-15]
CAD_FILES/Optical mount for lens _ mirror _ prism - 1004337/files/lens_mount3.stl
57.0 x 112.2 x 19.0

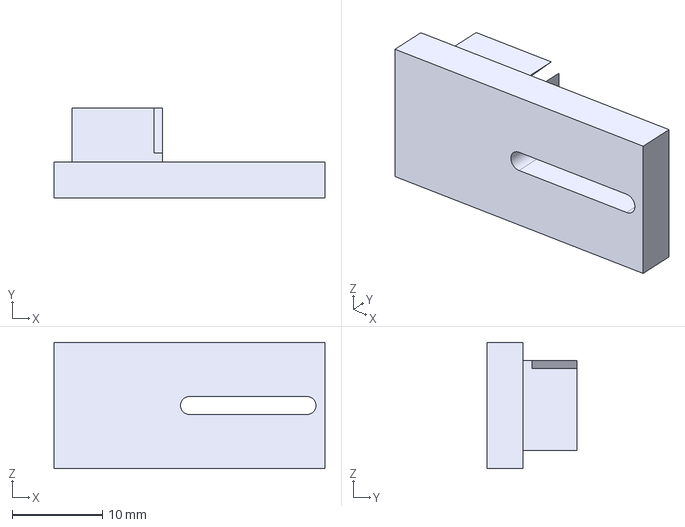
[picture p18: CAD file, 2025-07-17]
CAD_FILES/LaserProjectorV2/hardware/cad/BeamAligner.STEP
30.0 x 10.0 x 14.0 mm

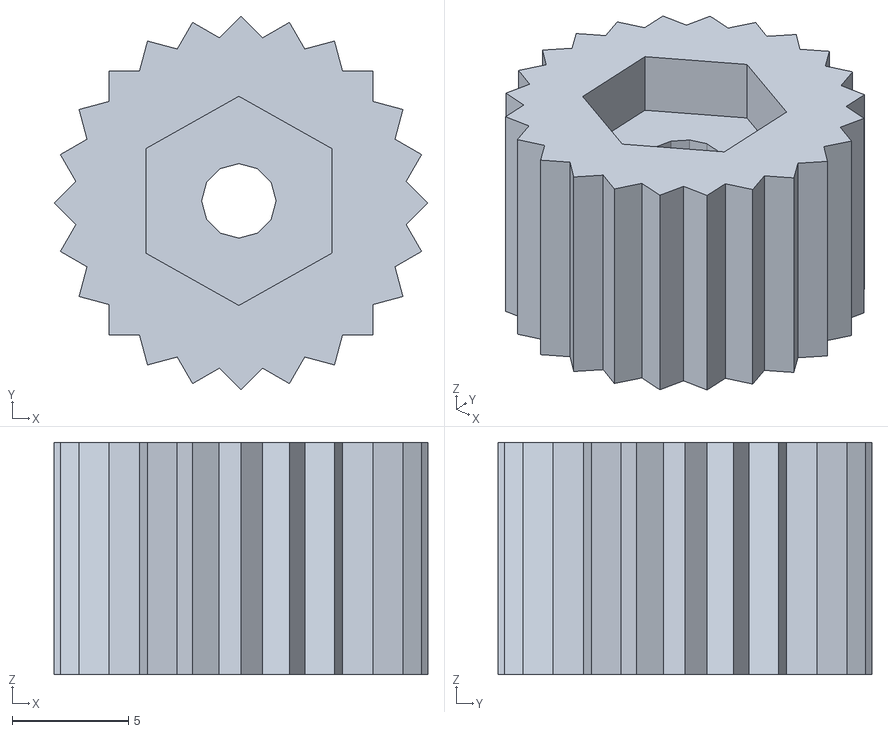
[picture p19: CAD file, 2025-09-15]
CAD_FILES/Optical mount for lens _ mirror _ prism - 1004337/files/lens_mount3_part_4.stl
16.1 x 16.1 x 10.0

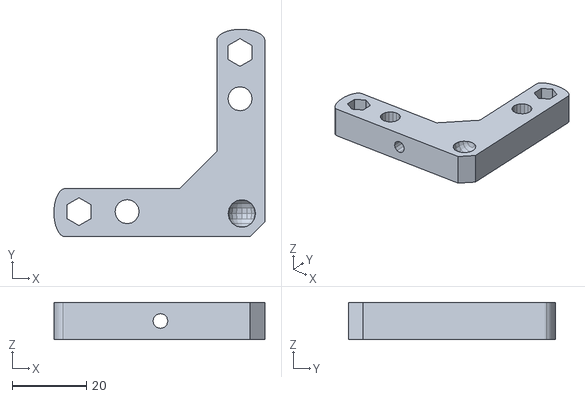
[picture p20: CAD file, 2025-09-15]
CAD_FILES/Optical mount for lens _ mirror _ prism - 1004337/files/lens_mount3_part2.stl
57.0 x 56.0 x 10.0

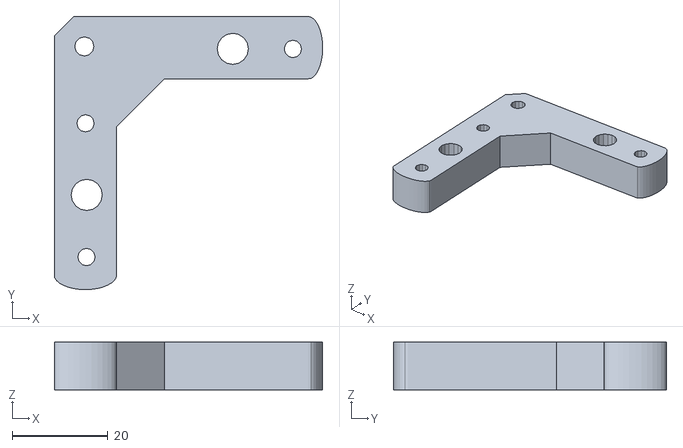
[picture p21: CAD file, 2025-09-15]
CAD_FILES/Optical mount for lens _ mirror _ prism - 1004337/files/lens_mount3_part_3.stl
56.0 x 57.0 x 10.0

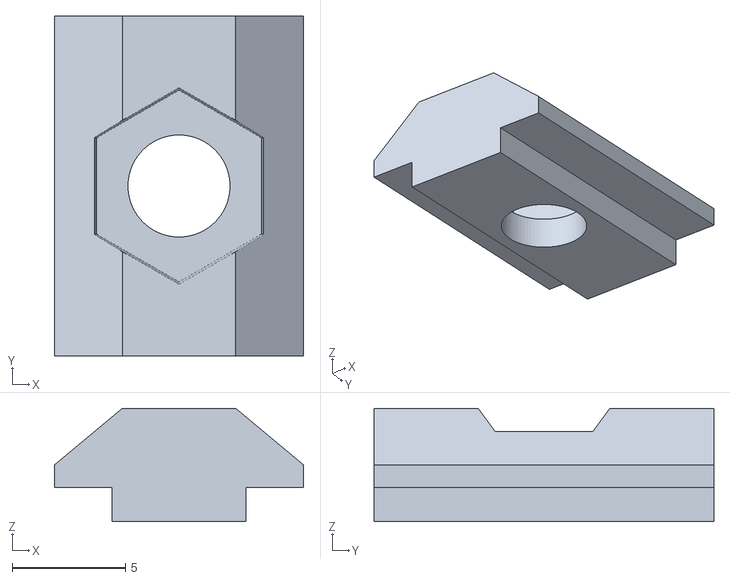
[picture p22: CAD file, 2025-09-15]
CAD_FILES/Optics Bench Lensholder - 2336754/files/tnut.STL
11.0 x 15.0 x 5.00

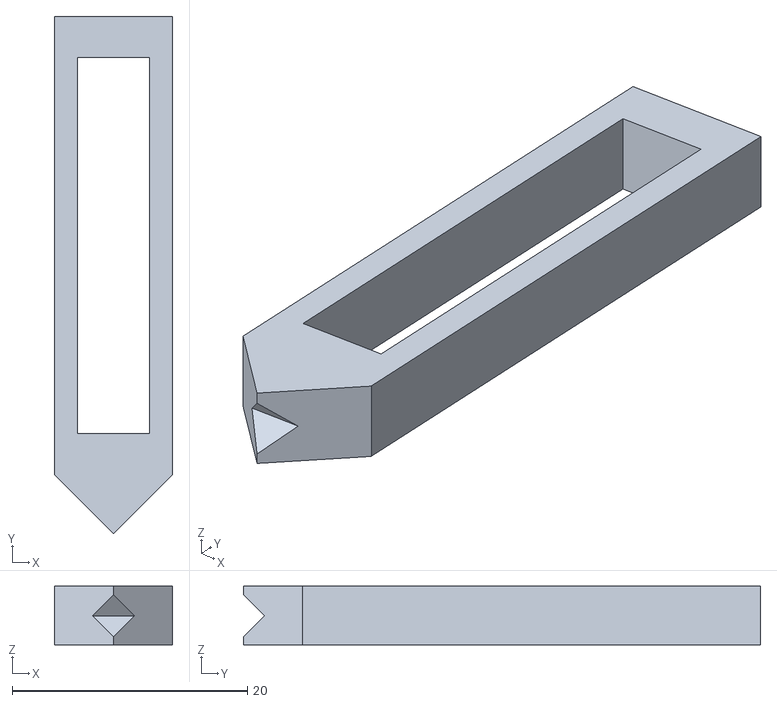
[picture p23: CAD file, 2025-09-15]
CAD_FILES/Optics Bench Lensholder - 2336754/files/slider.stl
10.0 x 44.0 x 5.00

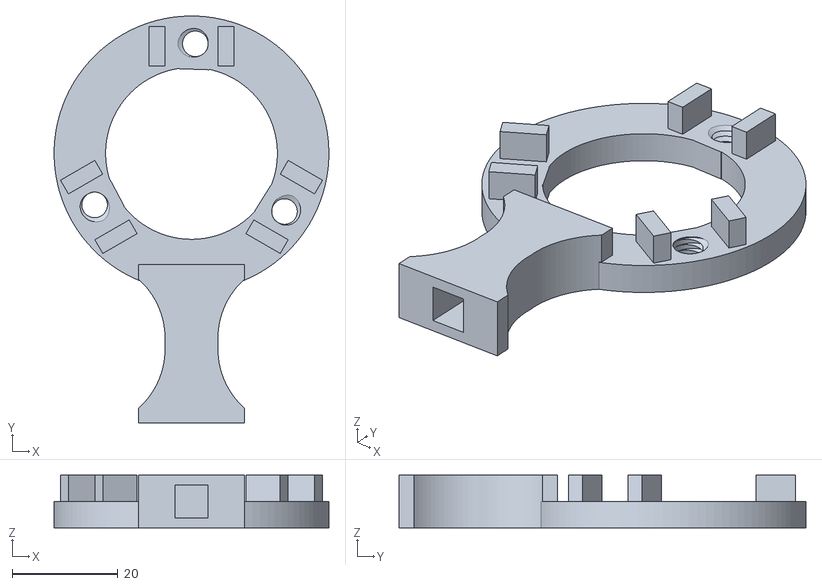
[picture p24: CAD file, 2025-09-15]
CAD_FILES/Optics Bench Lensholder - 2336754/files/lens_holder.stl
52.0 x 77.0 x 10.0

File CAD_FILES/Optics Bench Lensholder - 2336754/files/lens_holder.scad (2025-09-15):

include <threads_v2.scad>
use <knurledFinishLib_v2.scad>


$fn=100;


// The maximum lens size that the holder should accomodate.  This scales
// the diameter of the lens holder, as well as the length of the sliders
maxLensDiameter = 23.64;

// Height of stand. Does not include the diameter of the lens holder
height = 25;

// Length of bolt. Shouldn't be any reason to change this.
boltLength = 15;

// A scaling factor applied to the bolt.  Smaller values may be required
// if threads are not printed well.  NOTE: this applies a scaling in all
// axis to the bolt, so too much scaling will distort the threads
// sufficiently that they no longer mesh!
boltScaling = 0.95;

// The height of the extrusion nut may need to be scaled for a tight
// fit, depending on your extrusion and printer
extrusionNutHeightScaling = 1;



// PRIVATE -- don't edit these variables
outerDiameter = maxLensDiameter + (14.18*2);
outerRadius = outerDiameter/2;
innerDiameter = outerDiameter - (9.75*2);
    
module holder() {
    union() {
        difference() {
            cylinder(d=outerDiameter,h=5);
            translate([0,0, -1]) cylinder(d=innerDiameter,h=12);
            for (i = [0:2]) {
                rotate([0,0,120*i + 59]) translate([0,(innerDiameter/2)+5,-2]) 
                    cylinder(d=6.1,h=22);
            }
        }
    }  
    for (i = [0:2]) {
        difference() {
             rotate([0,0,120*i + 60]) 
                translate([-8,-(7.5/2) + (innerDiameter/2)+4, 5])
                cube([16,7.5,5]);
            rotate([0,0,120*i + 60]) 
                translate([-5,-(7.5/2) + (innerDiameter/2)+3.9, 4])
                cube([10,9,7]);
        }
        
        rotate([0,0,120*i + 58]) translate([0,(innerDiameter/2)+4.5,0]) 
            MetricNut(6, 5);
    }
}


module stand() {
    union() {
        difference() {
            toleranceWidth = 5.9*1.05;
            offset = (10-toleranceWidth)/2;
            union() {
                // stalk
                translate([0,0,0]) cube([10,10, height+3]);
                
                 // bottom pedestal
                difference() {
                    translate([0,0,height+5]) mirror([0,0,1]) difference() {
                        translate([-5,0,height-10]) cube([20,10, 15]);
                        translate([-15,11,height-9]) 
                            rotate([90,90,0]) cylinder(d=30,h=12);
                        translate([15+10,11,height-9]) 
                            rotate([90,90,0]) cylinder(d=30,h=12);
                    }
                }
            }
            translate([offset, offset,-1]) 
                cube([toleranceWidth, toleranceWidth ,height]);
        }
        
        // top pedestal
        difference() {
            translate([-5,0,height-10]) cube([20,10, 15]);
            translate([-15,11,height-9]) rotate([90,90,0]) cylinder(d=30,h=12);
            translate([15+10,11,height-9]) rotate([90,90,0]) cylinder(d=30,h=12);
        }
    }
}

module slider() {
    outerLength = outerRadius + 4 + 9;
    innerLength = outerLength - 7;
    //slider
        union() {
            difference() {
                translate([-5,-(25/2) + 21, 0]) 
                    cube([10,outerLength,5]);
                translate([-6.1/2,-(18/2) + 21, -1])
                    cube([6.1,innerLength,7]);
            }
            difference() {
                rotate([0,0,0]) translate([0,3.5,2.5]) {
                    b = 7.1;
                    h = 7.1;
                    w = 5;

                    //Start with an extruded triangle
                    rotate(a=[0,0,45])
                    linear_extrude(height = w, center = true, convexity = 10, twist = 0)
                    polygon(points=[[0,0],[h,0],[0,b]], paths=[[0,1,2]]);
                }
               rotate([45,0,0])  translate([-2.5,0.5,-2]) cube(5);
            }
        }
}

module complete_holder() {
    translate([0,0,outerRadius + height]) rotate([90,60,0]) holder();
    translate([-5,-10,0]) stand();
}

module extrusionNut() {
    scale([1,1,extrusionNutHeightScaling]) translate([0,0,5.6]) union() {
        difference() {
            union() {
                for (i = [0:5]) {
                    translate([0,2*i,0]) rotate([0,180,0]) import("tnut.stl", convexity=10);
                }
                
            }
            translate([-12,10,-10]) cube([15,20,10]);
        }
        difference() {
            translate([-8.5,2,-.5]) cube([5.9,5.9,height-10]);
            translate([-6,-1,2]) cube([1,5.9+4,height-10]); // slot
            translate([-5.5,10,2]) rotate([90,0,0]) cylinder(d=2,h=10); //relief
        }
        translate([-3,8,height-1.5-10]) rotate([90,0,0]) 
            cylinder(d=2.5,h=6);
        translate([-3-5,8,height-1.5-10]) rotate([90,0,0]) 
            cylinder(d=2.5,h=6);
        translate([-8,0,-5.60]) 
            cube([5,10,0.60]);
    }
}

module bolt() {
    scale([boltScaling,boltScaling,boltScaling]) intersection() {
        difference() {
            union() {
                MetricBolt(6, boltLength);
                translate([0,0,0]) knurl(k_cyl_hg = 6, k_cyl_od = 13);
            }
            translate([0,0,-3]) cylinder(d=14,h=3);
        }
        // Shave off some of the knurling, the points are painful!
        cylinder(d=12.5,boltLength+6);
    }
}



for (i= [0:2]) {
    translate([i*14.5,18,0])  bolt();
    translate([i*14.5,18 + 5,0]) slider();
    translate([i*14.5,18 - 15,0]) MetricWasher(6);
}

translate([-10,0,0]) extrusionNut();
translate([-outerRadius - 10,0,0]) rotate([-90,0,0]) complete_holder();

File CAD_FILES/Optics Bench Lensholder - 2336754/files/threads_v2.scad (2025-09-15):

// Created 2016-2017 by Ryan A. Colyer.
// This work is released with CC0 into the public domain.
// https://creativecommons.org/publicdomain/zero/1.0/
//
// http://www.thingiverse.com/thing:1686322


screw_resolution = 0.2;  // in mm


// Provides standard metric thread pitches.
function ThreadPitch(diameter) =
  (diameter <= 64) ?
    lookup(diameter, [
      [2, 0.4],
      [2.5, 0.45],
      [3, 0.5],
      [4, 0.7],
      [5, 0.8],
      [6, 1.0],
      [7, 1.0],
      [8, 1.25],
      [10, 1.5],
      [12, 1.75],
      [14, 2.0],
      [16, 2.0],
      [18, 2.5],
      [20, 2.5],
      [22, 2.5],
      [24, 3.0],
      [27, 3.0],
      [30, 3.5],
      [33, 3.5],
      [36, 4.0],
      [39, 4.0],
      [42, 4.5],
      [48, 5.0],
      [52, 5.0],
      [56, 5.5],
      [60, 5.5],
      [64, 6.0]
    ]) :
    diameter * 6.0 / 64;


// Provides standard metric hex head widths across the flats.
function HexAcrossFlats(diameter) =
  (diameter <= 64) ?
    lookup(diameter, [
      [2, 4],
      [2.5, 5],
      [3, 5.5],
      [3.5, 6],
      [4, 7],
      [5, 8],
      [6, 10],
      [7, 11],
      [8, 13],
      [10, 16],
      [12, 18],
      [14, 21],
      [16, 24],
      [18, 27],
      [20, 30],
      [22, 34],
      [24, 36],
      [27, 41],
      [30, 46],
      [33, 50],
      [36, 55],
      [39, 60],
      [42, 65],
      [48, 75],
      [52, 80],
      [56, 85],
      [60, 90],
      [64, 95]
    ]) :
    diameter * 95 / 64;

// Provides standard metric hex head widths across the corners.
function HexAcrossCorners(diameter) =
  HexAcrossFlats(diameter) / cos(30);


// Provides standard metric hex (Allen) drive widths across the flats.
function HexDriveAcrossFlats(diameter) =
  (diameter <= 64) ?
    lookup(diameter, [
      [2, 1.5],
      [2.5, 2],
      [3, 2.5],
      [3.5, 3],
      [4, 3],
      [5, 4],
      [6, 5],
      [7, 5],
      [8, 6],
      [10, 8],
      [12, 10],
      [14, 12],
      [16, 14],
      [18, 15],
      [20, 17],
      [22, 18],
      [24, 19],
      [27, 20],
      [30, 22],
      [33, 24],
      [36, 27],
      [39, 30],
      [42, 32],
      [48, 36],
      [52, 36],
      [56, 41],
      [60, 42],
      [64, 46]
    ]) :
    diameter * 46 / 64;

// Provides standard metric hex (Allen) drive widths across the corners.
function HexDriveAcrossCorners(diameter) =
  HexDriveAcrossFlats(diameter) / cos(30);

// Provides metric countersunk hex (Allen) drive widths across the flats.
function CountersunkDriveAcrossFlats(diameter) =
  (diameter <= 14) ?
    HexDriveAcrossFlats(HexDriveAcrossFlats(diameter)) :
    round(0.6*diameter);

// Provides metric countersunk hex (Allen) drive widths across the corners.
function CountersunkDriveAcrossCorners(diameter) =
  CountersunkDriveAcrossFlats(diameter) / cos(30);

// Provides standard metric nut thickness.
function NutThickness(diameter) =
  (diameter <= 64) ?
    lookup(diameter, [
      [2, 1.6],
      [2.5, 2],
      [3, 2.4],
      [3.5, 2.8],
      [4, 3.2],
      [5, 4.7],
      [6, 5.2],
      [7, 6.0],
      [8, 6.8],
      [10, 8.4],
      [12, 10.8],
      [14, 12.8],
      [16, 14.8],
      [18, 15.8],
      [20, 18.0],
      [22, 21.1],
      [24, 21.5],
      [27, 23.8],
      [30, 25.6],
      [33, 28.7],
      [36, 31.0],
      [42, 34],
      [48, 38],
      [56, 45],
      [64, 51]
    ]) :
    diameter * 51 / 64;
  

// This generates a closed polyhedron from an array of arrays of points,
// with each inner array tracing out one loop outlining the polyhedron.
// pointarrays should contain an array of N arrays each of size P outlining a
// closed manifold.  The points must obey the right-hand rule.  For example,
// looking down, the P points in the inner arrays are counter-clockwise in a
// loop, while the N point arrays increase in height.  Points in each inner
// array do not need to be equal height, but they usually should not meet or
// cross the line segments from the adjacent points in the other arrays.
// (N>=2, P>=3)
// Core triangles:
//   [j][i], [j+1][i], [j+1][(i+1)%P]
//   [j][i], [j+1][(i+1)%P], [j][(i+1)%P]
//   Then triangles are formed in a loop with the middle point of the first
//   and last array.
module ClosePoints(pointarrays) {
  function recurse_avg(arr, n=0, p=[0,0,0]) = (n>=len(arr)) ? p :
    recurse_avg(arr, n+1, p+(arr[n]-p)/(n+1));

  N = len(pointarrays);
  P = len(pointarrays[0]);
  NP = N*P;
  lastarr = pointarrays[N-1];
  midbot = recurse_avg(pointarrays[0]);
  midtop = recurse_avg(pointarrays[N-1]);

  faces_bot = [
    for (i=[0:P-1])
      [0,i+1,1+(i+1)%len(pointarrays[0])]
  ];

  loop_offset = 1;
  bot_len = loop_offset + P;

  faces_loop = [
    for (j=[0:N-2], i=[0:P-1], t=[0:1])
      [loop_offset, loop_offset, loop_offset] + (t==0 ?
      [j*P+i, (j+1)*P+i, (j+1)*P+(i+1)%P] :
      [j*P+i, (j+1)*P+(i+1)%P, j*P+(i+1)%P])
  ];

  top_offset = loop_offset + NP - P;
  midtop_offset = top_offset + P;

  faces_top = [
    for (i=[0:P-1])
      [midtop_offset,top_offset+(i+1)%P,top_offset+i]
  ];

  points = [
    for (i=[-1:NP])
      (i<0) ? midbot :
      ((i==NP) ? midtop :
      pointarrays[floor(i/P)][i%P])
  ];
  faces = concat(faces_bot, faces_loop, faces_top);

  polyhedron(points=points, faces=faces);
}



// This creates a vertical rod at the origin with external threads.  It uses
// metric standards by default.
module ScrewThread(outer_diam, height, pitch=0, tooth_angle=30, tolerance=0.4, tip_height=0, tooth_height=0, tip_min_fract=0) {

  pitch = (pitch==0) ? ThreadPitch(outer_diam) : pitch;
  tooth_height = (tooth_height==0) ? pitch : tooth_height;
  tip_min_fract = (tip_min_fract<0) ? 0 :
    ((tip_min_fract>0.9999) ? 0.9999 : tip_min_fract);

  outer_diam_cor = outer_diam + 0.25*tolerance; // Plastic shrinkage correction
  inner_diam = outer_diam - pitch/tan(tooth_angle);
  or = (outer_diam_cor < screw_resolution) ?
    screw_resolution/2 : outer_diam_cor / 2;
  ir = (inner_diam < screw_resolution) ? screw_resolution/2 : inner_diam / 2;
  height = (height < screw_resolution) ? screw_resolution : height;

  steps_per_loop_try = ceil(2*3.14159265359*or / screw_resolution);
  steps_per_loop = (steps_per_loop_try < 4) ? 4 : steps_per_loop_try;
  hs_ext = 3;
  hsteps = ceil(3 * height / pitch) + 2*hs_ext;

  extent = or - ir;

  tip_start = height-tip_height;
  tip_height_sc = tip_height / (1-tip_min_fract);

  tip_height_ir = (tip_height_sc > tooth_height/2) ?
    tip_height_sc - tooth_height/2 : tip_height_sc;

  tip_height_w = (tip_height_sc > tooth_height) ? tooth_height : tip_height_sc;
  tip_wstart = height + tip_height_sc - tip_height - tip_height_w;


  function tooth_width(a, h, pitch, tooth_height, extent) =
    let(
      ang_full = h*360.0/pitch-a,
      ang_pn = atan2(sin(ang_full), cos(ang_full)),
      ang = ang_pn < 0 ? ang_pn+360 : ang_pn,
      frac = ang/360,
      tfrac_half = tooth_height / (2*pitch),
      tfrac_cut = 2*tfrac_half
    )
    (frac > tfrac_cut) ? 0 : (
      (frac <= tfrac_half) ?
        ((frac / tfrac_half) * extent) :
        ((1 - (frac - tfrac_half)/tfrac_half) * extent)
    );


  pointarrays = [
    for (hs=[0:hsteps])
      [
        for (s=[0:steps_per_loop-1])
          let(
            ang_full = s*360.0/steps_per_loop,
            ang_pn = atan2(sin(ang_full), cos(ang_full)),
            ang = ang_pn < 0 ? ang_pn+360 : ang_pn,

            h_fudge = pitch*0.001,

            h_mod =
              (hs%3 == 2) ?
                ((s == steps_per_loop-1) ? tooth_height - h_fudge : (
                 (s == steps_per_loop-2) ? tooth_height/2 : 0)) : (
              (hs%3 == 0) ?
                ((s == steps_per_loop-1) ? pitch-tooth_height/2 : (
                 (s == steps_per_loop-2) ? pitch-tooth_height + h_fudge : 0)) :
                ((s == steps_per_loop-1) ? pitch-tooth_height/2 + h_fudge : (
                 (s == steps_per_loop-2) ? tooth_height/2 : 0))
              ),

            h_level =
              (hs%3 == 2) ? tooth_height - h_fudge : (
              (hs%3 == 0) ? 0 : tooth_height/2),

            h_ub = floor((hs-hs_ext)/3) * pitch
              + h_level + ang*pitch/360.0 - h_mod,
            h_max = height - (hsteps-hs) * h_fudge,
            h_min = hs * h_fudge,
            h = (h_ub < h_min) ? h_min : ((h_ub > h_max) ? h_max : h_ub),
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

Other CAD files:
CAD_FILES/Optics Bench Lensholder - 2336754/files/extrusion_nut.stl
CAD_FILES/Optics Bench Lensholder - 2336754/files/bolt.stl
CAD_FILES/Optics Bench Lensholder - 2336754/files/washer.stl
CAD_FILES/Optics Bench Lensholder - 2336754/files/knurledFinishLib_v2.scad
CAD_FILES/LaserProjectorV2/hardware/cad/BeamAligner.STL
CAD_FILES/LaserProjectorV2/hardware/cad/MirrorHolder.STL
CAD_FILES/LaserProjectorV2/hardware/cad/ScannerHolder.STL

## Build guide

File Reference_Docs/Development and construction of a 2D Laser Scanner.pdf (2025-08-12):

# Development and construction of a 2D Laser Scanner

## Niklas H

## October 11, 2020

## Contents

1 Introduction | 2
2 Theory | 2
3 Implementation | 4
4 Results | 8
5 Conclusion | 11
6 Prospect | 12
7 Acknowledgements | 12
References | 12

1

## 1 Introduction

Many laser scanning¹
systems for material processing today are based on galvanometeractuated mirror systems and utilize ber lasers (λ = 1064nm) for ecient and fast engraving on metals. However, galvanometers are expensive and complicated to drive. This projects goal is to create a similar system using stepper motors, which are very simple to use and laser diodes (λ = 650nm and λ = 445nm). The secondary goal is to create a cheap but accurate drive system which should be possible to build with minimal tools (3D-Printer, lathe (optional) and basic soldering equipment) from scratch. For this sake, two versions will be built, the rst one utilizing a low power laser diode and no f-theta lens for a safe proof-of-concept and the second one utilizing a high-power laser diode for engraving.
In this documentation, the mechanical, electrical, mathematical and programming side of the rst project will be discussed.

## 2 Theory

In this section, relevant theory will be discussed. The development of the scanner will be based on these details.

2.1 Laser diodes

Laser diodes are special semiconductors that emit spatially coherent and monochromatic light of a specic wavelength λ (laser beam). Laser diodes are relatively fragile components which electrically behave similar to normal diodes, meaning low resistance in one current direction and high resistance in the opposite direction. For laser diodes to work properly, they must be driven with a constant current²
. Therefore, it is good practice to use constant current sources and heatsinks for driving laserdiodes. Also, laser diodes oftentimes emit laser beams with relatively high divergence, so an optical collimator is required in order to reduce the divergence to a few mrad.

2.2 Stepper motors

Stepper motors reach high positioning accuracy by performing movements in discrete steps (usually 1.8

◦
). The appropriate winding currents are supplied by stepper motor drivers. These drivers are given two signals: STEP and DIR. One STEP pulse from the controller advances the motor position one step, whilst the DIR signal (low or high) indicates the direction. The accuracy can be improved by using special drivers which interpolate the rotation between poles (micro-stepping).

1The term scanning in this context refers to material processing (e.g. engraving) line-by-line 2Laser diodes are easily damaged by current spikes or excess heat

2

2.3 Optics of the scanner

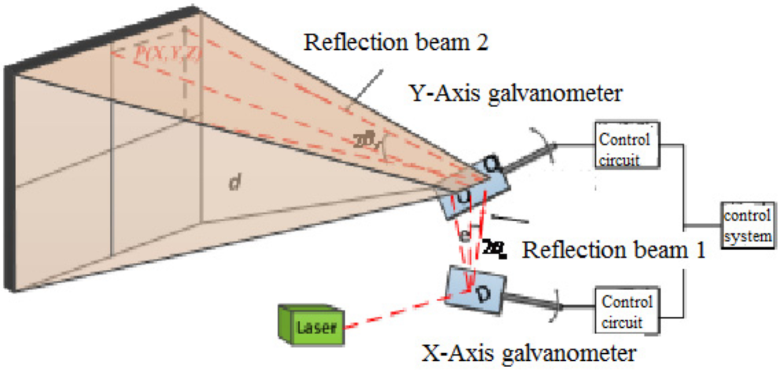
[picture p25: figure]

Figure 1: Model of the optical mirror system [Meng et al.(2019)Meng, Cao, Li, and Lv]

Because the scanner can only indirectly control the laser dot on the working plane by turning its mirrors, some sort of mathematical representation of this system must be derived. This representation will used for turning XY-directions into mirror rotation angles. From [Meng et al.(2019)Meng, Cao, Li, and Lv] we get the following equations:

x = e · tan(2θx) + tan(2θx) ·

p
d

2 + y

2 | (1)
y = d · tan(θy) | (2)

where x and y are the point coordinates on the plane, θx and θy are the rotations angles of the mirrors³
, e is the vertical distance between the mirror axes and d is the normal distance between the projection plane and the Y-mirror rotation axis.
Since x and y are given by the user (rather the gcode), equations 1 and 2 must be solved for θx and θy. These angles will be turned into step signals for the steppers. From equation 2 we can derive

θy =

arctan(

y
d

)
2 | (3)

From equation 1, θx can be found:

θx =

arctan
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
3More specically: θx is the angle between the laser beam and the rst reection beam minus 90◦ .
Similarly, θy is the angle between the rst and second reection beam minus 90◦

3

Looking at gure 1, x and y must be zero, when θx = θy = 0◦ 4 . Equations 3 and 4
conrm this.

## 3 Implementation

In this section, construction details of the galvo scanner will be explained.

3.1 Mechanics and Optics

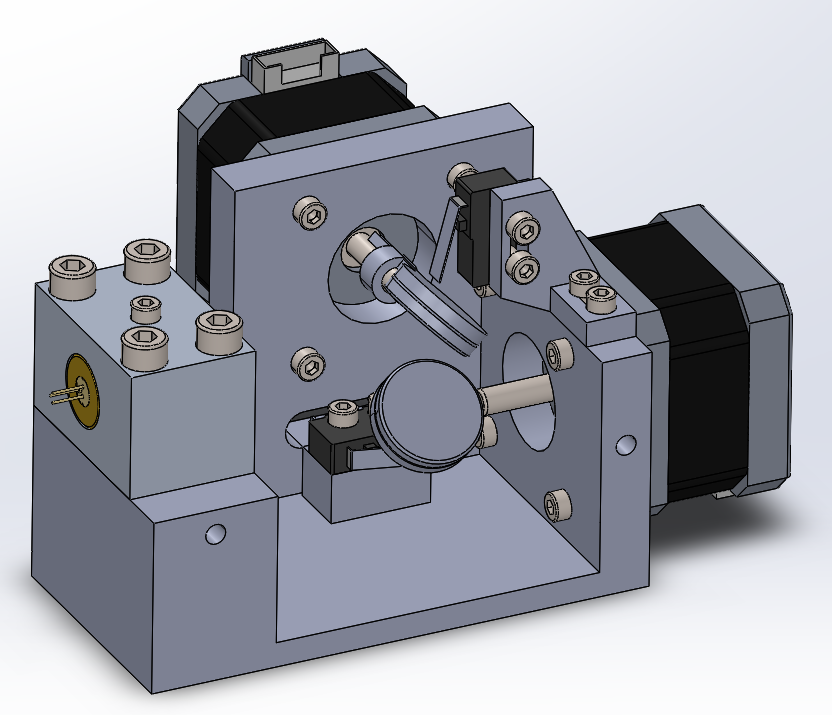
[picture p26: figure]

Figure 2: CAD-Rendering of the mechanical system

4with these angles, all beams are orthogonal. This conguration is referred to the neutral or home position.

4

The mechanics of this design are relatively simple: The mirrors are attached to stepper motors by glueing aluminium holders onto the at piece of the rotor and glueing the mirrors (in this case 20x3mm molybdenum mirrors) onto the holder and the rotor⁵
. The
motors are then screwed onto the 3D-printed base (PLA, 60% inll). This base also has features to screw on endswitches (for homing the mirrors) and the laserdiode array. The latter consists of a machined aluminium block into which the laserdiode holder (machined brass) ts. This holder also has a M9x0.5 thread for the collimator unit. The collimator can be adjusted via this thread.

3.2 Electronics

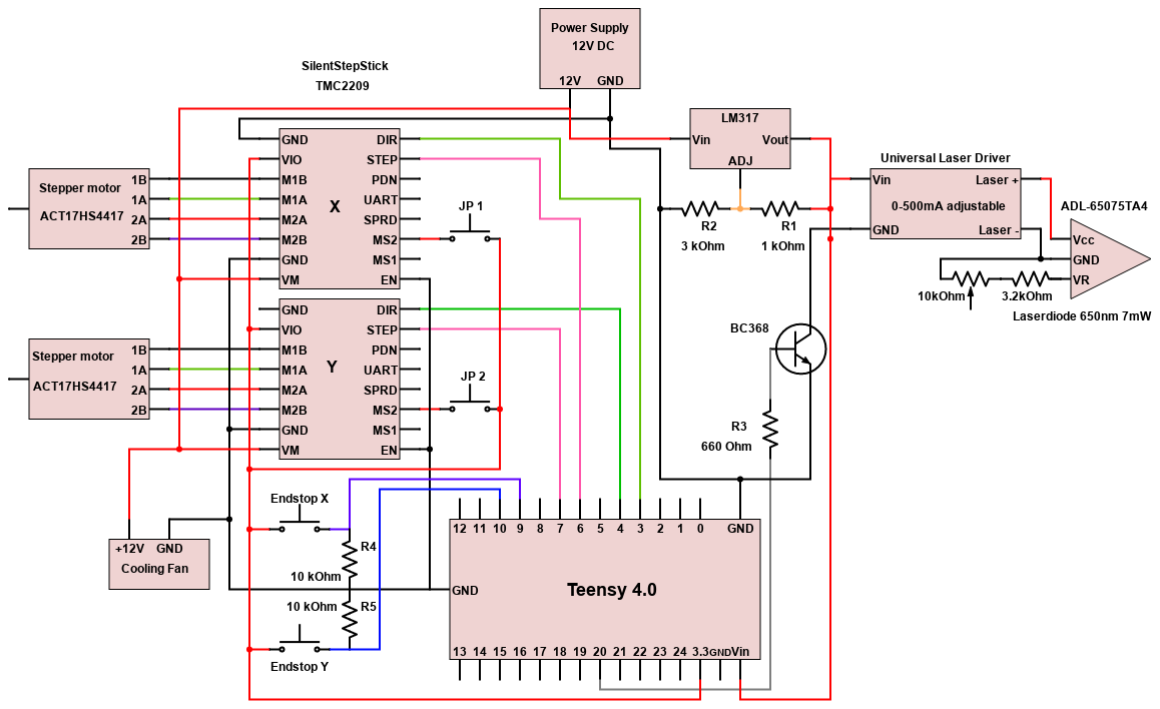
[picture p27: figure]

Figure 3: Wiring diagram for the system

Figure 3 shows the electrical diagram of the system. The stepper motors are Nema-17 ACT 17hs4417 steppers. The SilentStepSticks (containing Trinamic TMC2209 ICs) were chosen as drivers because of their high micro-stepping capabilities (up to 256), extremely low noise and relatively low cost (about 10 Euros or 12 USD per driver).
For the main controller, a Teensy 4.0 was chosen because of the extremely high clock

5The holders were machined and 3D-printed (PLA, 100% inll) to test the dierence in performance, but none was noticeable. The molybdenum mirrors are relatively heavy, but are the cheapest viable option available.

5

frequency of 600Mhz⁶ and its easy programmability through the Arduino IDE. It must be noted, that the Teensy 4.0 only tolerates 3.3V logic voltage.

Note: Teensy Boards and laserdiodes can be very fragile electrical components (multiple Teensies and Diodes were destroyed in this project), so it may be worth the money and eort to use an Arduino in order to test the circuits/code and use dummy loads for simulating laser diodes. Since the SilentStepStick-Drivers can tolerate 3.3V and 5V as logic voltages, the microcontrollers can be changed without changing the circuit. However, the footprints are not equal, so jumper cables are necessary for replacing the Teensy with an Arduino.

For driving the laserdiode, a special diode driver is used, which can supply 0-500mA of constant regulated current⁷
This driver circuit is activated by a NPN-Transistor (specially, a BC368). For calculating its base resistance R2, a base current of the BC368 transistor of IB = 5mA is selected [Sem(2007), p. 3]. Since the Teensy 4.0 logic voltage is 3.3V , a resistance value of R2 =

3.3V
5mA = 660Ω is selected.
The laser diode has three pins: Vcc, GND and VR. Vcc is connected to the output of the constant current source, GND is connected to the Laser - pin of the diode driver. VR is connected to Laser - via a resistance of 3kΩ (maximum power) - 13kΩ (minimum power), which is realised with xed resistors (3.2kΩ) in series with a linear potentiometer (10kΩ). The GND of the diode driver is connected to a transistor to switch it on or o. For supplying Vcc (5V) for the Teensy and the laser driver, a LM317 linear voltage regulator is used in the shown conguration. The resistors R1 and R2 can be computed as follows [lm3(2014), p. 10]:

Vout = 1.25 ·

1 +

R2
R1
(5)

Vout must be 5V and R1 is chosen to be 1kΩ. Therefore, R2 must be:

R2 =

Vout
1.25V

− 1

- R1 =
5V
1.25V

− 1

- 1000Ω = 3000Ω | (6)

R4 and R5 are pull-down resistors that draw the pin state of pins 9 and 10 (pins for the endstops) to the low state to prevent undened behaviour.
JP1 and JP2 are jumpers that set the microstepping mode of the stepper motor drivers to 1
8

(jumper disconnected) or 1
64 (jumper connected).

6
In comparison, an Arduino Nano only has 16MHz clock frequency!

7
It is possible to use a LM317 and correct resistors for a constant current source. This was tested in this project, but resulted in a lot of destroyed laser diodes, which is why a complete driver circuit was bought.

6

3.3 Code

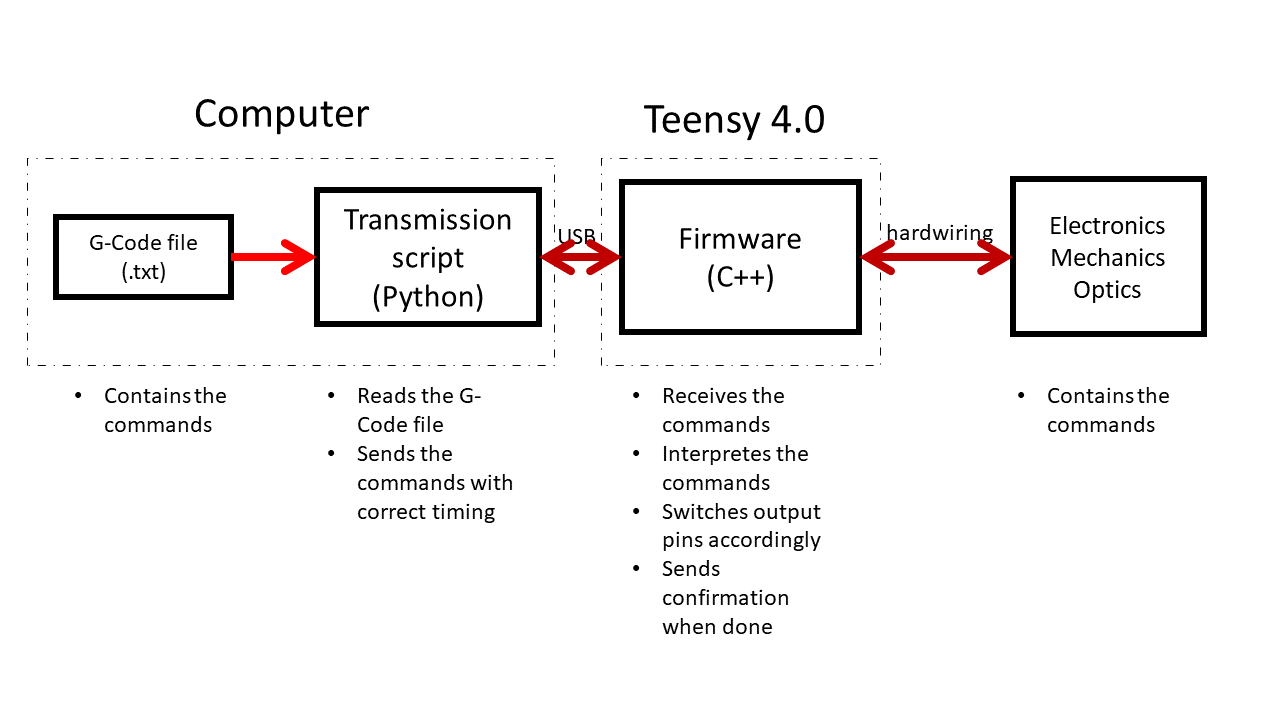
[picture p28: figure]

Figure 4: A simplied diagram of the program architecture

The programm architecture (see gure 4) consists of three main parts: The teensy rmware, a python script for Gcode transmission and the G-Code itself.

Firmware The rmware is the most critical part of the architecture: It interpretes the received (via Serial) G-Code commands and coordinates all of the outputs and inputs, such as step and direction signals and the transistor base for the laser or the endstop signals. Because it is directly compiled onto the Teensy via the Arduino IDE, it is written in C++.
The rmware supports the following G-Code commands: G0, G1, G2, G3, G28, G60, G61, M3, M4, M5, M201, M203. 8 The rmware sends a short conrmation (usually: OK), when the command is processed. If it included stepper movement (such as G0), the conrmation will only be sent when steppers have reached their target position.

Transmission script The transmission script is a Python script that reads the G-Code le from a specied location on the PC. The gcode is read, encoded and sent via a Serial connection (USB). Before the next line is sent, the script waits for a conrmation from the rmware. This makes sure that no command is sent before the rmware is nished

8For a detailled explanation and syntax details, see the GalvoStep wiki at https://github.com/NiklasHammerstone/GalvoStep

7

processing the previous command. This loop is repeated until no G-Code commands are left to send.

G-Code The G-Code le is a simple text le (.txt) which contains the command lines. It is critical that each line only contains one command.

## 4 Results

4.1 General functionality

The proposed functionality was realised. The prototype can be given commands by sending G-Code commands via the Arduino IDE Serial Monitor or a Python script⁹
. The
commands are executed instantly. No delay between commands is perceivable when a whole G-Code le is executed via the Python script. This results in a smooth movement of the laser spot.
A G-Code le drawing a heart shape was tested with step frequencies of 2000steps
s

up
to 20000steps
s

and a distance from the projection plane of about 200mm. At about 10000 − 12000steps
s

the moving spot started to look like a (more or less) stationary image¹⁰, with the shape of the image still not being noticeably distorted. At about 15000−18000steps
s

the image stationarity was satisfactory, but mechanical vibrations led to a distorted image. The results of this test can be seen in gures 5 and 6. Note that

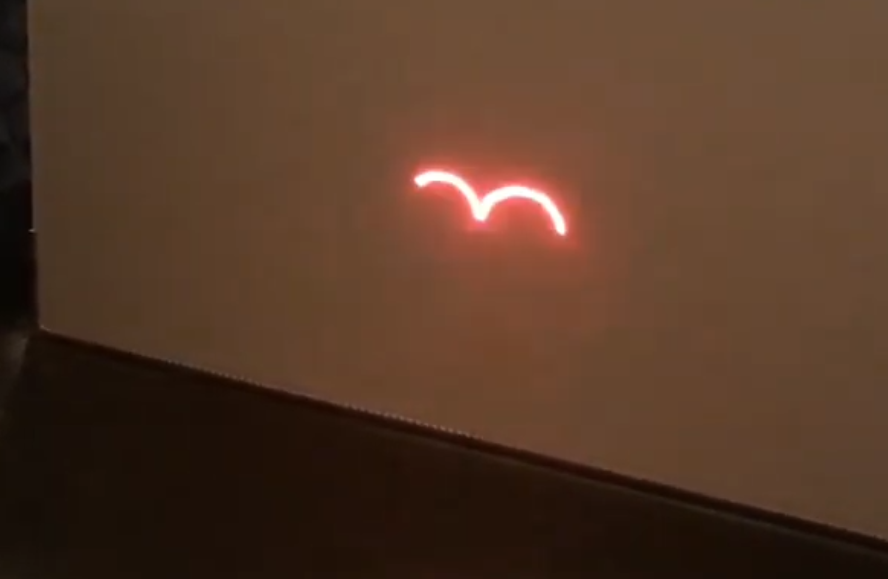
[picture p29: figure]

Figure 5: Arcs of the projected heart at 8000steps
s

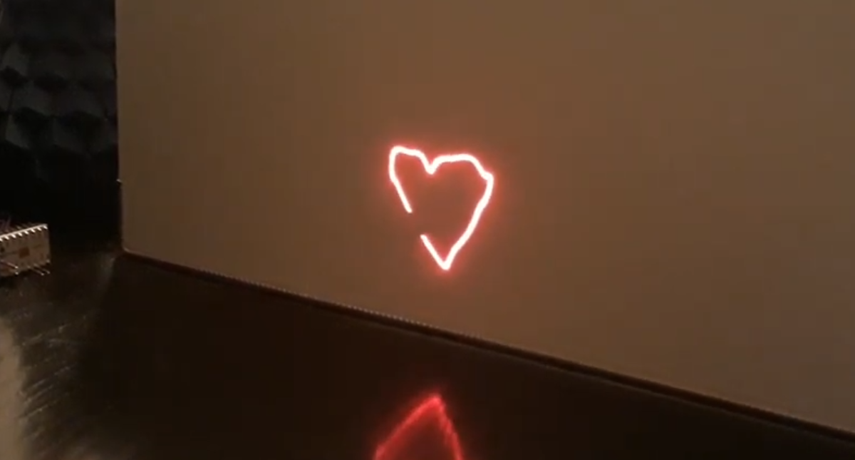
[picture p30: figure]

Figure 6: Almost entire heart at 20000steps
s

the rolling shutter of the camera is quite fast, which is why only the picture at about 20000steps
s

is (almost) completely visible in one photo. However the dierence of the arcs alone should convey the dience of the whole picture.

9The code les can be downloaded via GitHub: https://github.com/NiklasHammerstone/GalvoStep 10This is only true for the naked eye. Also, the border step frequency is dependent on the size of the image, the background, the laser intensity and the general lighting of the room.

8

4.2 Accuracy and precision

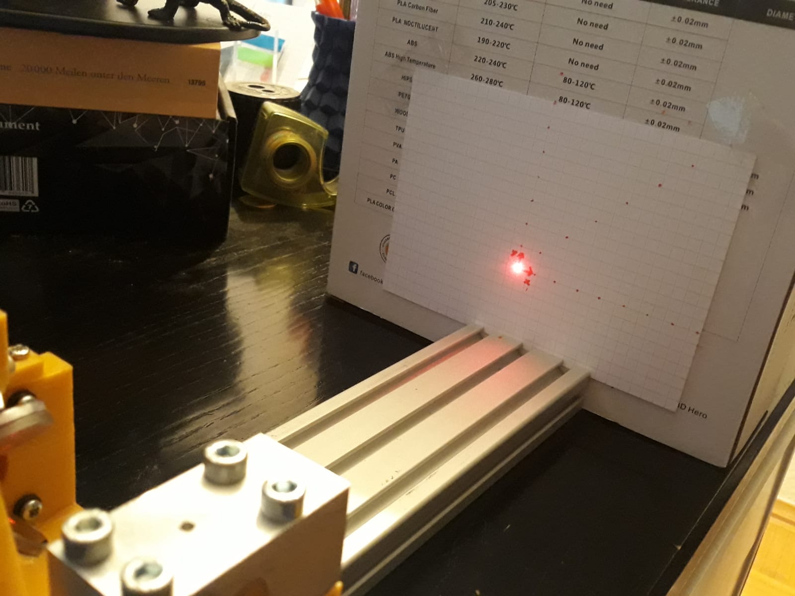
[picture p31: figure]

Figure 7: Snapshot of the testing procedure

In order to test the accuracy of the prototype, the following procedure was performed:

1. Place the machine in front of a plane with a dened distance D.
2. Home the mirrors.
3. Move the laser point in 10mm steps in X-, Y-, and XY direction (from -20 to +80) with speed F.¹¹
4. Mark the actual laser spot carefully with a pen for each step (see gure 7)¹²
5. After the testing is done, measure the actual distances of the spots from the origin point.

11An example command for testing the XY direction would be G0 X20 Y20. In this test, X and Y coordinates were always equal to reach an ideal line of slope 1.
12Since the prototype utilizes a 7mW laser diode, the laser itself is too weak to mark the paper by itself.

9

From the Y-, X- and XY, the average and maximum dierence from the ideal coordinates are computed. For the XY-coordinates, average slope and intercept were calculated to analyze the linearity of the system.

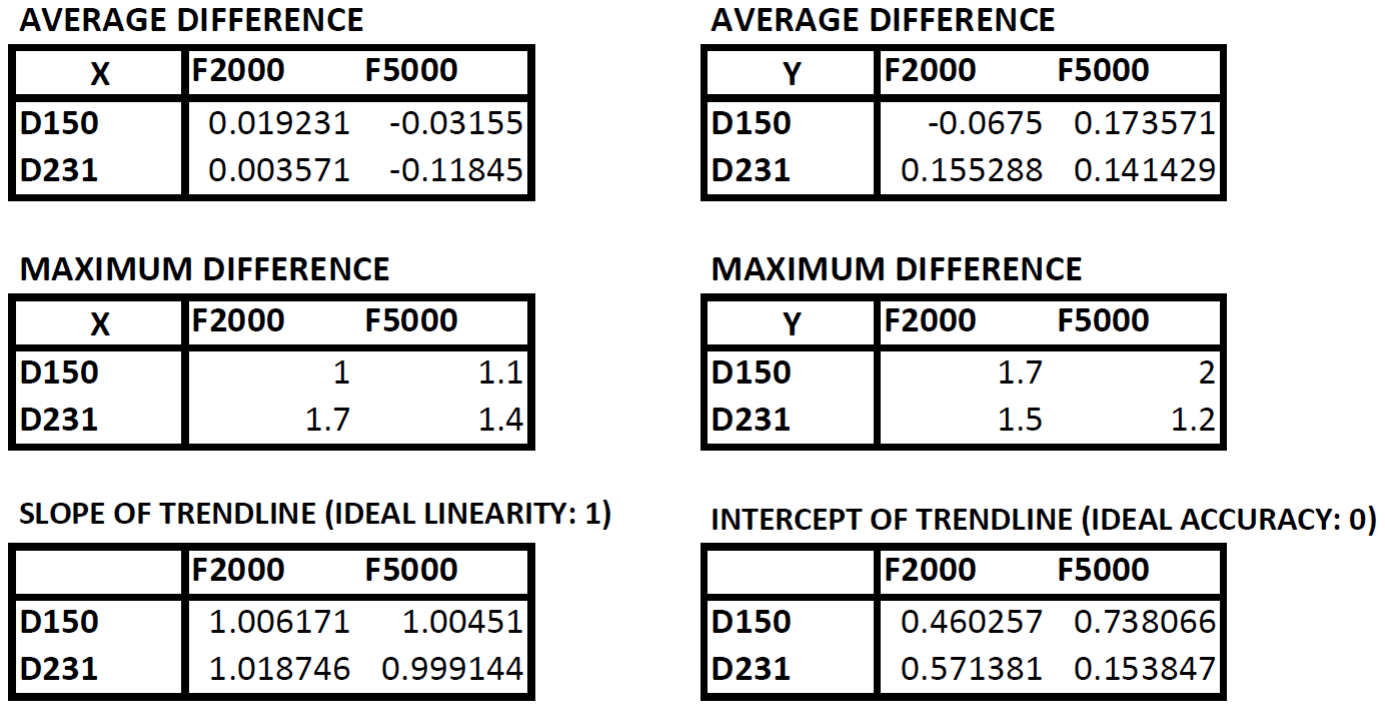
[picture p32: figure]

Figure 8: Results of the accuracy analysis

In gure 8 the results of the mentioned tests are shown. It is expected, that the average and maximum dierences (representing positional accuracy) would rise with rising distance D and feedrate F. However, no such trends can be seen from the data. The average dierence is consistently lower than 0.2mm, but the absolute maximum is 2mm. This suggests relatively high accuracy, but low precision. This is veried by the slope of the trendline for the XY-point testing. The highest dierence from the ideal slope of 1 (since the same values were used for X and Y coordinates simultaneously) was 0.018mm
mm

, suggesting high accuracy. However, the intercepts of the trendlines (ideal would be zero) dier widely from zero, with dierences going as high as 0.738mm, suggesting low precision. This result suggests that the machine is working correctly¹³, but is lacking the mechanical alignment for high precision.
Furthermore, the repeatability of the endstops and backlash of the motors was tested. For the repeatability test of the endstops, the machine was homed ten times (homing speed: 500steps
s

) and the spot osets were noted. The average dierence was about 0.3mm with a maximum of 2mm, resulting in a arc accuracy of 0.5

◦
. These inaccuracies
are most likely due to the cheap mechanical endstops used.
For the backlash test, the machined was homed and the spot was moved by 80mm back

13Working correctlyrefers to the mathematic model being correct and the physical, electrical and optical design being expedient in theory

10 and forth multiple times in X and Y directions. As expected (because no parts are present that could induce backlash), no backlash was perceivable.

4.3 Flaws of the testing methodology

It must be noted that the proposed method of testing has inherent inaccuracies: Since the laser can not mark paper by itself, it is necessary to use a pen, but as soon as the pen is brought into position, it blocks the laser beam. This way its necessary for the operator to visually remember where the spot was. The marked spot can be checked by removing the pen and therefore unblocking the pen, but since both the spot and the pen marking have a diameter of approximately 1.5mm¹⁴, this method can not guarantee results within about half of that range (0.5 − 0.9mm). This can be partly compensated by making sure that the caliper blades are positioned in the exact middle (which itself is only possible within a few tenths of a millimeter) of the pen marking when measuring the points. Also, the paper pieces used for this test did bow out by approximately 1mm, which is unideal. In conclusion, the dierence of laser spot and pen marking and the measuring inaccuracies add up to such a big margin of error (approximately ±1mm) that the exact values of the point coordinates are relatively useless for accuracy analysis. However, since the presented aws are unsystematic and randomn (except for the bow of the paper), the averages (average distance, slope and intercept of trendline) should be more conclusive.
These aws can be elimininated entirely by using a more powerful laser which can mark wood by itself. This would eliminate the pen method with all its aws and inaccuracies and only leave the direct measuring inaccuracies of the calipers, which are usually within 0.02 − 0.1mm.

## 5 Conclusion

In conclusion, the goal of a proof-of-concept for a steppermotor-actuated galvoprojector was reached. The machine can be used via G-Code like a normal CNC-machine (e.g. 3D-printer, CNC-Router) and can draw gures with step speeds of up to 20000steps
s

,
depending on how much distortion is acceptable for the user. Since this machine cannot compete with laser projectors using real galvoactuators, its most probable usecase would be engraving with speeds unreachable for most CO2 or diode daser machines currently on the market. Since the precision of the current prototype is quite limited (as shown in the chaper Results), more work is required to be able compete with normal benchtop laser engravers (see Prospect).

14The actual laser spot is much smaller than this, but appears to be larger due the light being scattered and dispersed in the surrounding paper

11

## 6 Prospect

In the following versions of this machine, the steppermotors and endstops will be upgraded. The base will be re-designed to t the new high-power laser module and the mirrors will be replaced. An F-theta objective might be added to increase light intensity at the working plane and therefore engraving speed. Finally, safety precautions (Enclosure with laser windows and doorswitch) will be added to shield the laser beam. The electronics will not be changed much, since they worked without problems¹⁵

## 7 Acknowledgements

Special thanks to the members of the forum www.laser-engravers.de, especially VDX and Gewindestange, without which a lot more laser diodes would have been destroyed in the process of this project.

## References

[Sem(2007)] NPN − BC368; PNP − BC369 Amplier Transistors. https://www.onsemi.com/pub/Collateral/BC368-D.PDF, 2007.

[lm3(2014)] LM317 - 3-TerminalAdjustableRegulator. https://www.st.com/en/power-management/lm317.html, 2014.

[Meng et al.(2019)Meng, Cao, Li, and Lv] Xianyu Meng, Guohua Cao, Xue Li, and Qiongying Lv. 2-D Scanning Galvanometer Error Analysis and Its Correction. Journal of Physics: Conference Series, 1345:022068, 2019. ISSN 1742-6588. doi: \url{10.1088/1742-6596/1345/2/022068}.

15Maybe a PCB will be designed and manufactured for the schematic.

12

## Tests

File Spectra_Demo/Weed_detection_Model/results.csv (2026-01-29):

epoch | time | train/box_loss | train/cls_loss | train/dfl_loss | metrics/precision(B) | metrics/recall(B) | metrics/mAP50(B) | metrics/mAP50-95(B) | val/box_loss | val/cls_loss | val/dfl_loss | lr/pg0 | lr/pg1 | lr/pg2 | lr/pg3 | lr/pg4 | lr/pg5 | lr/pg6 | lr/pg7
1 | 53.4337 | 2.98851 | 3.80208 | 1.43453 | 0.17426 | 0.372 | 0.25583 | 0.10826 | 1.75199 | 1.65865 | 0.97158 | 0.00165625 | 0.000552082 | 0.00165625 | 0.000552082 | 0.00165625 | 0.000552082 | 0.00165625 | 0.000552082
2 | 76.5728 | 2.56836 | 2.0675 | 1.20181 | 0.42799 | 0.4725 | 0.45078 | 0.23261 | 1.84764 | 1.5731 | 0.98904 | 0.00325744 | 0.00108581 | 0.00325744 | 0.00108581 | 0.00325744 | 0.00108581 | 0.00325744 | 0.00108581
3 | 96.3039 | 2.44561 | 1.90281 | 1.14437 | 0.44651 | 0.63259 | 0.44239 | 0.20422 | 1.842 | 1.5454 | 0.97605 | 0.00479263 | 0.00159754 | 0.00479263 | 0.00159754 | 0.00479263 | 0.00159754 | 0.00479263 | 0.00159754
4 | 115.638 | 2.34717 | 1.76582 | 1.10808 | 0.54639 | 0.51953 | 0.50645 | 0.25375 | 1.85992 | 1.46261 | 0.97492 | 0.00470394 | 0.00156798 | 0.00470394 | 0.00156798 | 0.00470394 | 0.00156798 | 0.00470394 | 0.00156798
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

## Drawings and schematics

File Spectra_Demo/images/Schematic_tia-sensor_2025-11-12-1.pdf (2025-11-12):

A | A

1

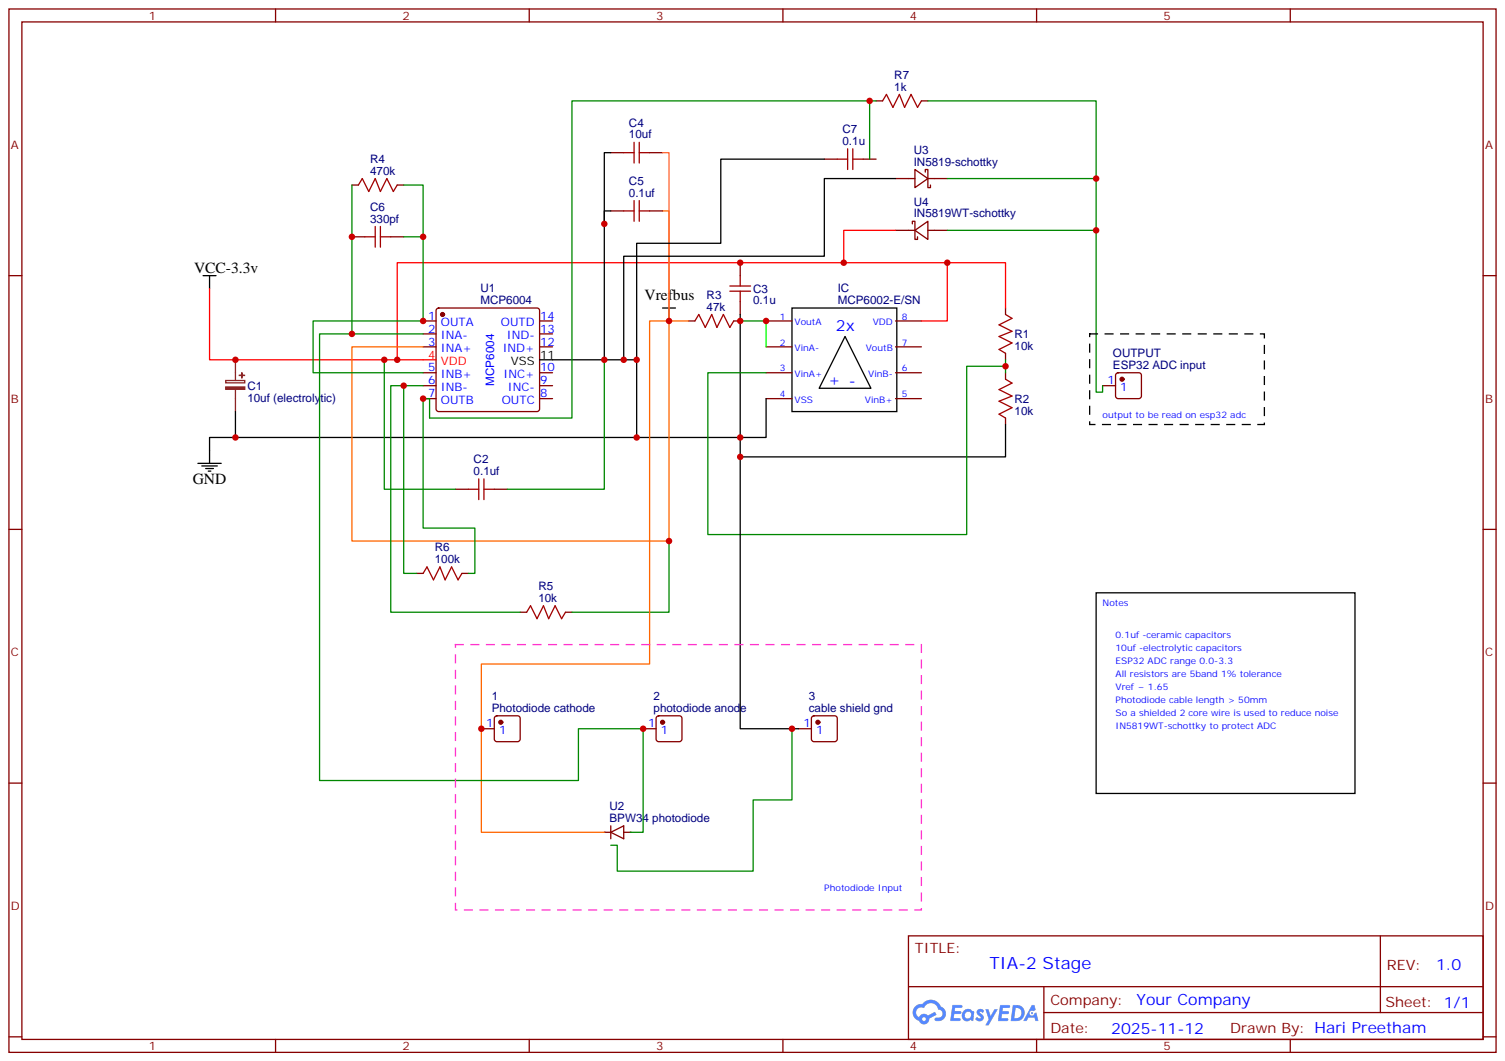
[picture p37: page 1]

output to be read on esp32 adc

0.1uf -ceramic capacitors
10uf -electrolytic capacitors
ESP32 ADC range 0.0-3.3
All resistors are 5band 1% tolerance
Vref ~ 1.65
Photodiode cable length > 50mm
So a shielded 2 core wire is used to reduce noise
IN5819WT-schottky to protect ADC

Drawn By: Hari Preetham

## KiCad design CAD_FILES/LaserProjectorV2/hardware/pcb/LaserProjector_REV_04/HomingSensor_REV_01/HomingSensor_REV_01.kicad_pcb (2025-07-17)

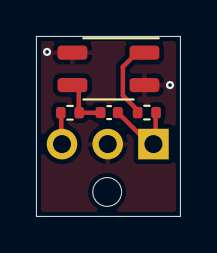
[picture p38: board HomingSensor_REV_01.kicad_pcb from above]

Board: 2 copper layers, 8.0 x 10.0 mm, 5 parts (1 on the bottom side), 5 nets.

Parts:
C1: 10nF; C_0402_1005Metric
J2: Connector; PinSocket_1x03_P2.54mm_Vertical
R1: 100R; R_0402_1005Metric
R2: 220R; R_0402_1005Metric
U1: QRE1113; OnSemi_CASE100CY

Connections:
+3V3: C1.1, J2.1, R1.2
GND: J2.2, U1.2, U1.4
unnamed: C1.2, R2.2, U1.3
unnamed: R1.1, U1.1
OUT: J2.3, R2.1

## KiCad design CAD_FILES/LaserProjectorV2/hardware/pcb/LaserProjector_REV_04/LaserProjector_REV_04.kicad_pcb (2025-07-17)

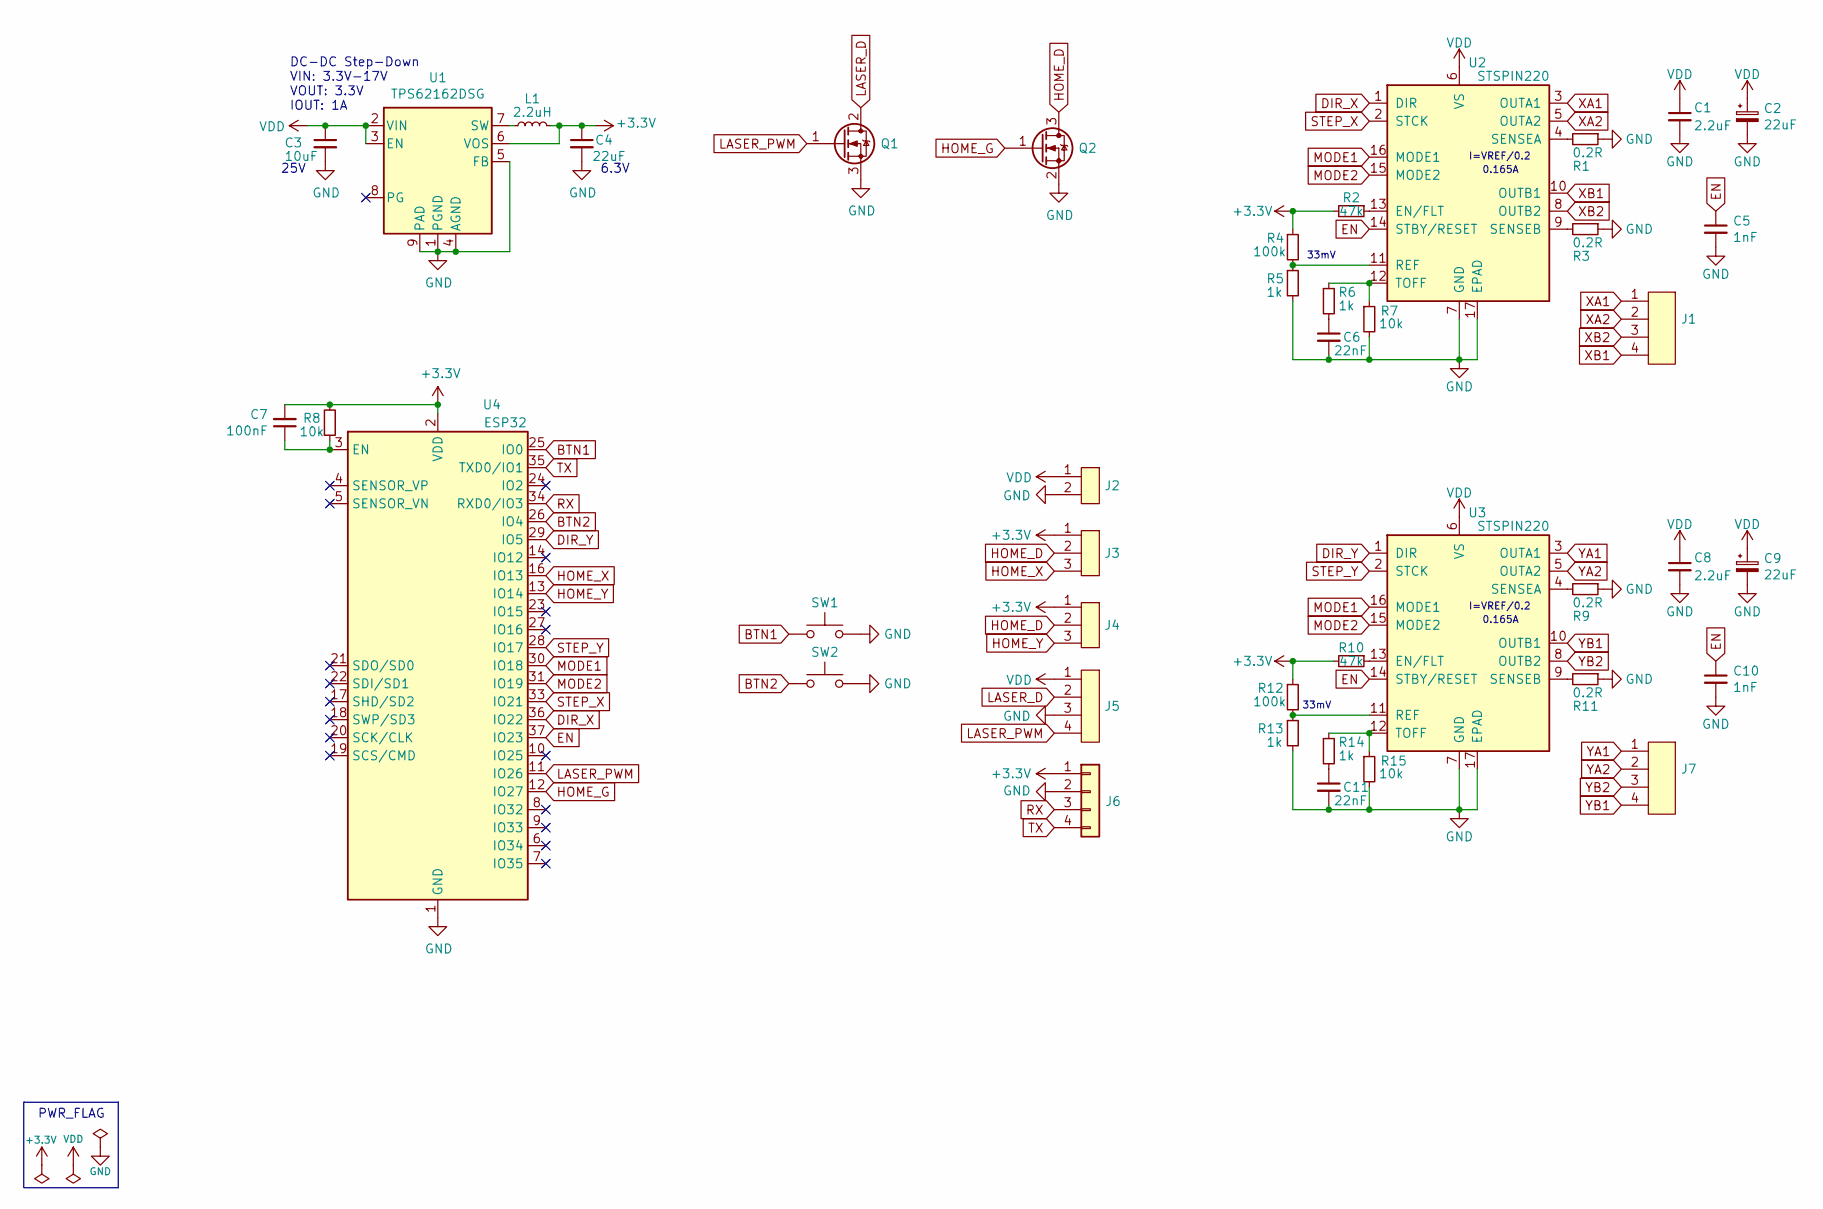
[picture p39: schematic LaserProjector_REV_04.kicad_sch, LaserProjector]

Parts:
C1, C8: 2.2uF; C_0603_1608Metric; MPN GRM188R61H225KE11D
C2, C9: 22uF; CP_Elec_6.3x5.8; MPN EEEHBH220UAP
C3: 10uF; C_0805_2012Metric; MPN CL21A106KAYNNNE
C4: 22uF; C_0805_2012Metric; MPN C2012X5R0J226MT000N
C5, C10: 1nF; C_0402_1005Metric; MPN GCM155R71H102KA37D
C6, C11: 22nF; C_0402_1005Metric; MPN GRM155R71E223JA61D
C7: 100nF; C_0402_1005Metric; MPN CC0402KRX7R7BB104
J1, J7: J_Molex-PicoBlade-4P-P1.25mm; Molex_PicoBlade_53047-0410_1x04_P1.25mm_Vertical; MPN 0530470410
J2: JST-XH-B2B; JST_XH_B2B-XH-A_1x02_P2.50mm_Vertical; MPN B2B-XH-A(LF)(SN)
J3, J4: J_Molex-PicoBlade-3P-P1.25mm; Molex_PicoBlade_53047-0310_1x03_P1.25mm_Vertical; MPN 0530470310
J5: JST-XH-B4B; JST_XH_B4B-XH-A_1x04_P2.50mm_Vertical; MPN B4B-XH-A(LF)(SN)
J6: Conn_01x04; PinHeader_1x04_P2.54mm_Vertical
L1: 2.2uH; VLCF4020; MPN VLCF4020T-2R2N1R7
Q1: NCE2060K; TO-252-2; MPN NCE2060K
Q2: NMOS; SOT-23; MPN NTR4501NT1G
R1, R3, R9, R11: 0.2R; R_2512_6332Metric; MPN WW25WR200FTL
R2, R10: 47k; R_0402_1005Metric; MPN RC0402FR-0747KL
R4, R12: 100k; R_0402_1005Metric; MPN RT0402BRE07100KL
R5, R6, R13, R14: 1k; R_0402_1005Metric; MPN 0402WGF1001TCE
R7, R8, R15: 10k; R_0402_1005Metric; MPN RT0402BRD0710KL
SW1, SW2: EVPAA602W; SW_EVPAA; MPN EVPAA602W
U1: TPS62162DSG; WSON-8-1EP_2x2mm_P0.5mm_EP0.9x1.6mm_ThermalVias; MPN TPS62162DSG
U2, U3: STSPIN220; MPN STSPIN220
U4: ESP32; ESP32-WROOM-32

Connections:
+3V3: C4.1, C7.2, J3.1, J4.1, J6.1, L1.2, R2.2, R4.1, R8.2, R10.2, R12.1, U1.6 (VOS), U4.2 (VDD)
BTN1: SW1.1, SW1.3, U4.25 (IO0); also elsewhere on the board
BTN2: SW2.1, SW2.3, U4.26 (IO4); also elsewhere on the board
DIR_X: U2.1 (DIR), U4.36 (IO22)
DIR_Y: U3.1 (DIR), U4.29 (IO5)
EN: C5.1, C10.1, U2.14 (STBY/RESET), U3.14 (STBY/RESET), U4.37 (IO23)
GND: C1.2, C2.2, C3.2, C4.2, C5.2, C6.2, C8.2, C9.2, C10.2, C11.2, J2.2, J5.3, J6.2, Q1.3 (S), Q2.2 (S), R1.1, R3.1, R5.2, R7.2, R9.1, R11.1, R13.2, R15.2, SW1.2, SW1.4, SW2.2, SW2.4, U1.1 (PGND), U1.4 (AGND), U1.5 (FB), U1.8 (PG), U1.9 (PAD), U2.7 (GND), U2.17 (EPAD), U3.7 (GND), U3.17 (EPAD), U4.1 (GND), U4.15 (GND), U4.38 (GND), U4.39 (GND); also elsewhere on the board
HOME_D: J3.2, J4.2, Q2.3 (D)
HOME_G: Q2.1 (G), U4.12 (IO27)
HOME_X: J3.3, U4.16 (IO13)
HOME_Y: J4.3, U4.13 (IO14)
LASER_D: J5.2, Q1.2 (D)
LASER_PWM: J5.4, Q1.1 (G), U4.11 (IO26)
MODE1: U2.16 (MODE1), U3.16 (MODE1), U4.30 (IO18)
MODE2: U2.15 (MODE2), U3.15 (MODE2), U4.31 (IO19)
unnamed: C6.1, R6.2
unnamed: C7.1, R8.1, U4.3 (EN)
unnamed: C11.1, R14.2
unnamed: L1.1, U1.7 (SW)
unnamed: R1.2, U2.4 (SENSEA)
unnamed: R2.1, U2.13 (EN/FLT)
unnamed: R3.2, U2.9 (SENSEB)
unnamed: R4.2, R5.1, U2.11 (REF)
unnamed: R6.1, R7.1, U2.12 (TOFF)
unnamed: R9.2, U3.4 (SENSEA)
unnamed: R10.1, U3.13 (EN/FLT)
unnamed: R11.2, U3.9 (SENSEB)
unnamed: R12.2, R13.1, U3.11 (REF)
unnamed: R14.1, R15.1, U3.12 (TOFF)
RX: J6.3, U4.34 (RXD0/IO3)
STEP_X: U2.2 (STCK), U4.33 (IO21)
STEP_Y: U3.2 (STCK), U4.28 (IO17)
TX: J6.4, U4.35 (TXD0/IO1)
VDD: C1.1, C2.1, C3.1, C8.1, C9.1, J2.1, J5.1, U1.2 (VIN), U1.3 (EN), U2.6 (VS), U3.6 (VS)
XA1: J1.1, U2.3 (OUTA1)
XA2: J1.2, U2.5 (OUTA2)
XB1: J1.4, U2.10 (OUTB1)
XB2: J1.3, U2.8 (OUTB2)
YA1: J7.1, U3.3 (OUTA1)
YA2: J7.2, U3.5 (OUTA2)
YB1: J7.4, U3.10 (OUTB1)
YB2: J7.3, U3.8 (OUTB2)

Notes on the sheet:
0.165A
PWR_FLAG
25V
6.3V
33mV
I=VREF/0.2
DC-DC Step-Down VIN: 3.3V-17V VOUT: 3.3V IOUT: 1A

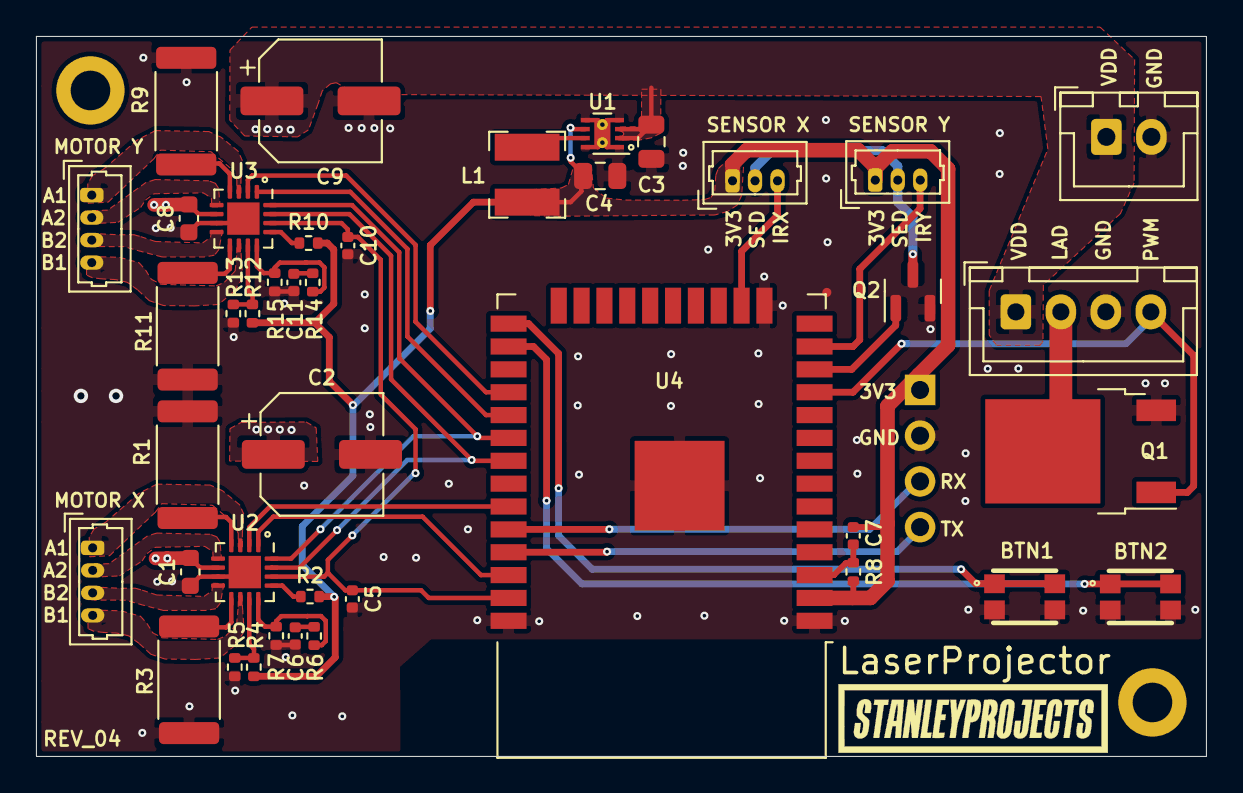
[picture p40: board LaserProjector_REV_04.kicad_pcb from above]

Board: 2 copper layers, 65.0 x 40.0 mm, 42 parts (0 on the bottom side), 42 nets.

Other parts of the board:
BTN1, BTN2: EVPAA602W; SW_EVPAA

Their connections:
BTN1: BTN1.1, BTN1.3; also elsewhere on the board
BTN2: BTN2.1, BTN2.3; also elsewhere on the board
GND: BTN1.2, BTN1.4, BTN2.2, BTN2.4; also elsewhere on the board

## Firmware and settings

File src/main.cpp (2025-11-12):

#include <Arduino.h>

void setup() {
  Serial.begin(115200); 
}

void loop() {

  const int samples = 10; // take 10 readings and average
  int accumulator = 0;

  for(int i = 0; i < samples; i++) {
    accumulator += analogRead(34);
    delay(2); // tiny delay so ADC settles a bit
  }

  int rawValue = accumulator / samples; // integer average

  float voltage = rawValue * (3.3 / 4095.0);

  Serial.print("Raw ADC Avg: ");
  Serial.print(rawValue);
  Serial.print("\t | \tVoltage: ");
  Serial.println(voltage, 4);

  delay(200); 
}

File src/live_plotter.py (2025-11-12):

import serial
import matplotlib.pyplot as plt
import matplotlib.animation as animation
from collections import deque

# --- YOU MUST CHANGE THIS ---
# Find your port in Arduino IDE (Tools -> Port). Examples: 'COM3' or '/dev/tty.usbserial-0001'
SERIAL_PORT = '/dev/ttyUSB0'  
BAUD_RATE = 115200
MAX_DATA_POINTS = 200 # How many data points to show on the plot at once.

# --- SCRIPT STARTS HERE ---
print(f"Attempting to connect to {SERIAL_PORT}...")
try:
    ser = serial.Serial(SERIAL_PORT, BAUD_RATE, timeout=1)
except serial.SerialException as e:
    print(f"Error: Could not open serial port. {e}")
    print("Check the port name and make sure the Arduino Serial Monitor is closed.")
    exit()

print("Successfully connected. Starting live plot...")
print("Close the plot window to stop the script.")

data = deque(maxlen=MAX_DATA_POINTS)
fig, ax = plt.subplots(figsize=(12,6))
line, = ax.plot([], [])
ax.set_ylim(0, 4095)
ax.set_xlim(0, MAX_DATA_POINTS)
ax.set_title("Live ESP32 ADC Reading")
ax.set_xlabel("Time (samples)")
ax.set_ylabel("Raw ADC Value (0-4095)")
ax.grid(True)

# This text object will display the range of the current data
range_text = ax.text(0.02, 0.95, '', transform=ax.transAxes, verticalalignment='top')

def update(frame):
    try:
        serial_line = ser.readline().decode('utf-8').strip()
        if serial_line:
            adc_value = int(serial_line)
            data.append(adc_value)
            line.set_data(range(len(data)), data)
            
            if len(data) > 10:
                min_val = min(data)
                max_val = max(data)
                variation = max_val - min_val
                
                # Update the Y-axis to zoom in on the action
                ax.set_ylim(min_val - 20, max_val + 20)
                # Update the text with the current variation
                range_text.set_text(f'Variation (Max-Min): {variation} counts')

    except (ValueError, UnicodeDecodeError):
        pass # Ignore bad data
        
    return line, range_text

ani = animation.FuncAnimation(fig, update, blit=True, interval=10)
plt.show()

ser.close()
print("Serial port closed.")

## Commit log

2025-07-17 firmware test and samples
    [BeamAligner.STEP, BeamAligner.STL, HomingSensor_REV_01.kicad_pcb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]
2025-09-15 cad added to technical report
    [bolt.stl, complete_set.stl, extrusion_nut.stl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]
2025-09-26 open loop testing
    [bolt.stl, complete_set.stl, extrusion_nut.stl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]
2025-11-12 added a schematic for TIA sensro
2025-11-15 added pyqtgraph to simulate perfect galvo
    [pyvenv.cfg]
2025-11-15 Stop tracking .software-only env file
    [pyvenv.cfg]
2025-11-22 checkpoint : added laser source, reflection on blue mirror works
2025-12-03 Revise operational power and speed details
    Updated operational parameters and corrected capitalization in the README.
2026-01-29 added camera calibration, modified engine.py
    [results.csv]
2026-01-30 added more demo files, created requirements.txt
    [results.csv]
